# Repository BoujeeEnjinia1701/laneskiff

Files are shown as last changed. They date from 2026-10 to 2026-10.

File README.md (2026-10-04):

# LaneSkiff

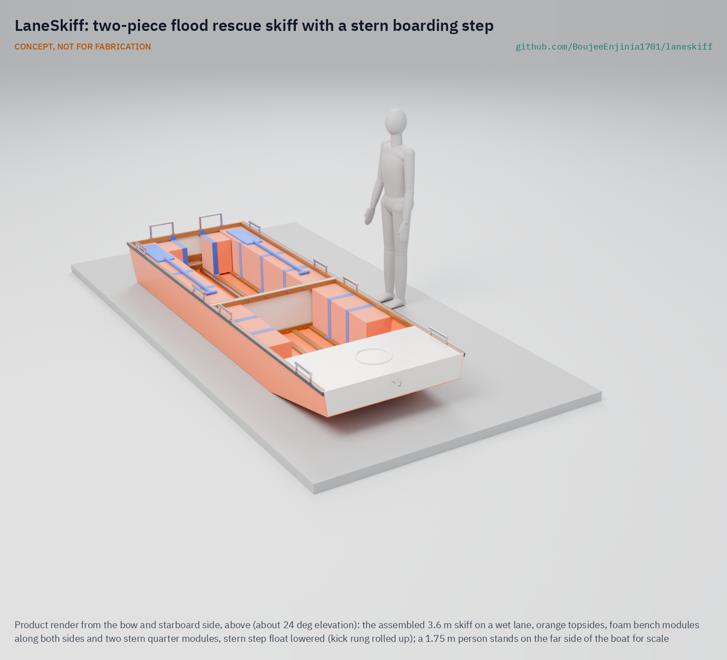
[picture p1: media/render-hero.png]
LaneSkiff: two-piece flood rescue skiff with a stern boarding step


     

**Area:** Situational field hardware · **TRL:** 3 of 9 (proof of concept on paper) · **Value-engineering target:** USD 1,500 (estimated cost of the constructable design USD 1,961) · **Difficulty:** 3 of 5

A flat-bottomed flood rescue boat two people carry into flooded lanes, with a floating stern step so people can climb in from waist-deep water.

> CONCEPT, NOT FOR FABRICATION. LaneSkiff is a TRL 3 design on paper: it has not been built or tested, and it is not certified rescue equipment.

## Concept rationale

Flood rescue in lanes is slow and awkward for boats built for open water. Hard boats are heavy to carry in, tip when someone climbs over the side, and sit too high for a person standing in waist-deep water. LaneSkiff is a flat-bottomed skiff sized for lanes: two people carry it in, and a crew pushes it along with a pole or paddles. A floating step at the stern centre lets people climb aboard over the end, where the boat is least likely to heel, and built-in buoyancy keeps it level and afloat even when it is swamped.

The hull splits into two rigid halves that bolt together, so it travels in a small vehicle and each half can be carried by one or two people. A material substitution table gives build paths in plywood and epoxy, aluminium sheet and plastic sheet, so local boatbuilders can make it with what they have. A fixed, forward-only fin drive is an optional add-on for longer transits; the core boat needs no engine. Payload is set at a realistic 5 to 8 times hull mass for a rigid hull.

## Burning platform

About 1.81 billion people, 23% of the world's population, are directly exposed to 1-in-100-year floods, and 89% of them live in low and middle income countries; India alone accounts for about 390 million ([Rentschler et al., Nature Communications, 2022](https://www.nature.com/articles/s41467-022-30727-4)). Drowning accounts for 75% of deaths in flood disasters ([WHO](https://www.who.int/health-topics/floods/drowning---key-facts)). In the 2018 Kerala floods about 800,000 people were displaced and many were stranded while rescuers worked with hundreds of boats ([CBS News, 2018](https://www.cbsnews.com/news/kerala-historic-floods-india-rescue-efforts-continue-hundreds-killed-2018-08-19/)).

The boats that exist are either costly, heavy or hard to board. A purpose-built inflatable rescue craft such as the Oceanid RDC costs USD 4,900 ([Oceanid](https://oceanid.com/RDC-Pricing-Specifications.html)). A 12 ft aluminium jon boat such as the Lund 1240 starts at USD 1,694 and weighs 107 lb (49 kg), but is rated for two people ([Lund](https://www.lundboats.com/families/jon-boat/1240.html)). Larger flood skiffs carry eight but weigh about 245 kg ([MetalBoatKits](https://metalboatkits.com/product/19-foot-6m-flood-rescue-skiff-new/)), too much to carry into a lane. None of them gives a person in waist-deep water a stable way in.

## Where it could be used

### By industry

| Industry | Use |
| --- | --- |
| Disaster response and civil defence | Lane-level evacuation where large boats cannot enter |
| Community and volunteer rescue groups | A boat local fishers and volunteers can build, store and carry to the flood |
| Humanitarian agencies | Prepositioned kits and local build programmes in flood-prone districts |
| Municipal services | Moving people, medicine and supplies through flooded streets |
| Small-scale fishing and boatbuilding | A design local boatyards can make and sell before the monsoon |
| Healthcare | Evacuating patients with limited mobility from flooded homes |

### By country or region

| Country or region | Why it matters there |
| --- | --- |
| India (Kerala) | The 2018 floods displaced about 800,000 people, with rescuers using hundreds of boats and nearly two dozen helicopters ([CBS News, 2018](https://www.cbsnews.com/news/kerala-historic-floods-india-rescue-efforts-continue-hundreds-killed-2018-08-19/)). |
| India (Bihar) | Villagers buy their own boats each flood season; small boats cost Rs 30,000 to 50,000 ([Gulf News, 2020](https://gulfnews.com/world/asia/india/india-floods-boost-boat-making-businesses-in-bihar-1.73026964)), so a cheaper, lighter local design matters. |
| Bangladesh | The August 2024 eastern floods affected 5.6 million people, with more than 500,000 seeking shelter as water submerged homes and streets ([UNICEF, 2024](https://www.unicef.org/press-releases/two-million-children-risk-worst-floods-three-decades-lash-through-eastern-bangladesh)). |
| Pakistan | The 2022 floods affected 33 million people and displaced 500,000 into relief camps ([UN News, 2022](https://news.un.org/en/story/2022/08/1125752)). |
| United States | In Hurricane Harvey, volunteer groups such as the Cajun Navy rescued people with jon boats, fishing boats, row boats, canoes and kayaks ([NBC News, 2017](https://www.nbcnews.com/storyline/hurricane-harvey/triumph-struggle-ragtag-cajun-navy-responds-houston-flood-n796991)), showing how much flood rescue relies on small craft. |

## What sparked the idea

During the Kerala floods of August 2018, Jaisal, a 32-year-old fisherman from Tanur in Malappuram, volunteered with a rescue team. Flat-bottomed boats are unstable and hard to board from the water, so he knelt in the floodwater and let women step on his back to climb in ([The Week, 2018](https://www.theweek.in/news/india/2018/08/20/kerala-fisherman-turns-stepping-stone-to-safety-literally.html)). His team rescued 17 families. LaneSkiff asks what boat would have made that sacrifice unnecessary: one with its own stable step, light enough to carry into the lanes where he worked.

## Problem

In urban and village floods, rescuers need a light boat they can carry into narrow flooded lanes, and people standing in waist-deep water need a way to climb into it without a rescuer kneeling as a step.

Full problem statement: [docs/01-problem.md](docs/01-problem.md)

## Concept

LaneSkiff is a flat-bottomed boat that two people carry into flooded lanes and push along with a pole or paddle. People in waist-deep water climb in using a floating step at the back, and it stays level and afloat even when swamped.

The constructable design is a 3.6 m punt-form skiff, 1.197 m wide over its rub strakes, stitched and glued from flat okoume plywood with softwood framing in two closed halves of 1.8 m that bolt together with eight M10 bolts and one spanner. Covered foam modules along both sides, two in the stern quarters and a foam bow box keep it nearly level when swamped (161 mm of freeboard at the transom). It is rated for five persons and draws 148 mm with them aboard. On paper, a person boarding over the stern step heels it 3.3 degrees, against 12.8 degrees over the side. The hull weighs 87.9 kg as drawn, still well over the 50 kg carry target, so each half is carried by two people with shoulder slings; see the [review note](docs/REVIEW.md).

Full design precis: [docs/02-concept.md](docs/02-concept.md) · Requirements: [docs/03-requirements.md](docs/03-requirements.md) · Calculations: [docs/04-calcs/01-sizing.md](docs/04-calcs/01-sizing.md) · Prototype build plan: [docs/05-build-plan.md](docs/05-build-plan.md) · Design decisions: [docs/06-design-decisions.md](docs/06-design-decisions.md)

## Key components

- Flat-bottom hull in two closed halves of okoume plywood and epoxy (6 mm bottom, 4 mm sides), each with its own bulkhead and softwood ring frame
- Eight M10 joint bolts into welded nut plates, two alignment pins
- Level flotation (LevelHull layout): covered foam bench modules along both sides and a foam bow box
- Stern-centre floating boarding step on strap hinges, with stop straps, a kick rung and two transom grab handles
- Eight carry handles and two padded shoulder slings
- Two-section push pole, two paddles, bow eye and bow line
- HDPE rub strakes and bottom skids
- Material substitution table: plywood and epoxy, aluminium sheet, HDPE sheet
- Optional fixed forward-only fin drive: not in the first prototype design (open decision)

## Building the prototype

The [prototype build plan](docs/05-build-plan.md) (LSK-BLD-001, plan, not yet built) shows a small boatyard how to build the first LaneSkiff component by component, with making sketches for fifteen made parts, close-ups of nine joints and a picture for each of seventeen assembly steps. The halves are stitched and glued from flat plywood panels, framed with softwood and glassed outside; the foam modules are cut with a knife and sewn into covers; the step is a glued float on strap hinges. No one is carried before the step, straps, handles and joint are proof-loaded and the boat passes load and swamp trials in calm, shallow water with a safety boat, which is TRL 4 work.

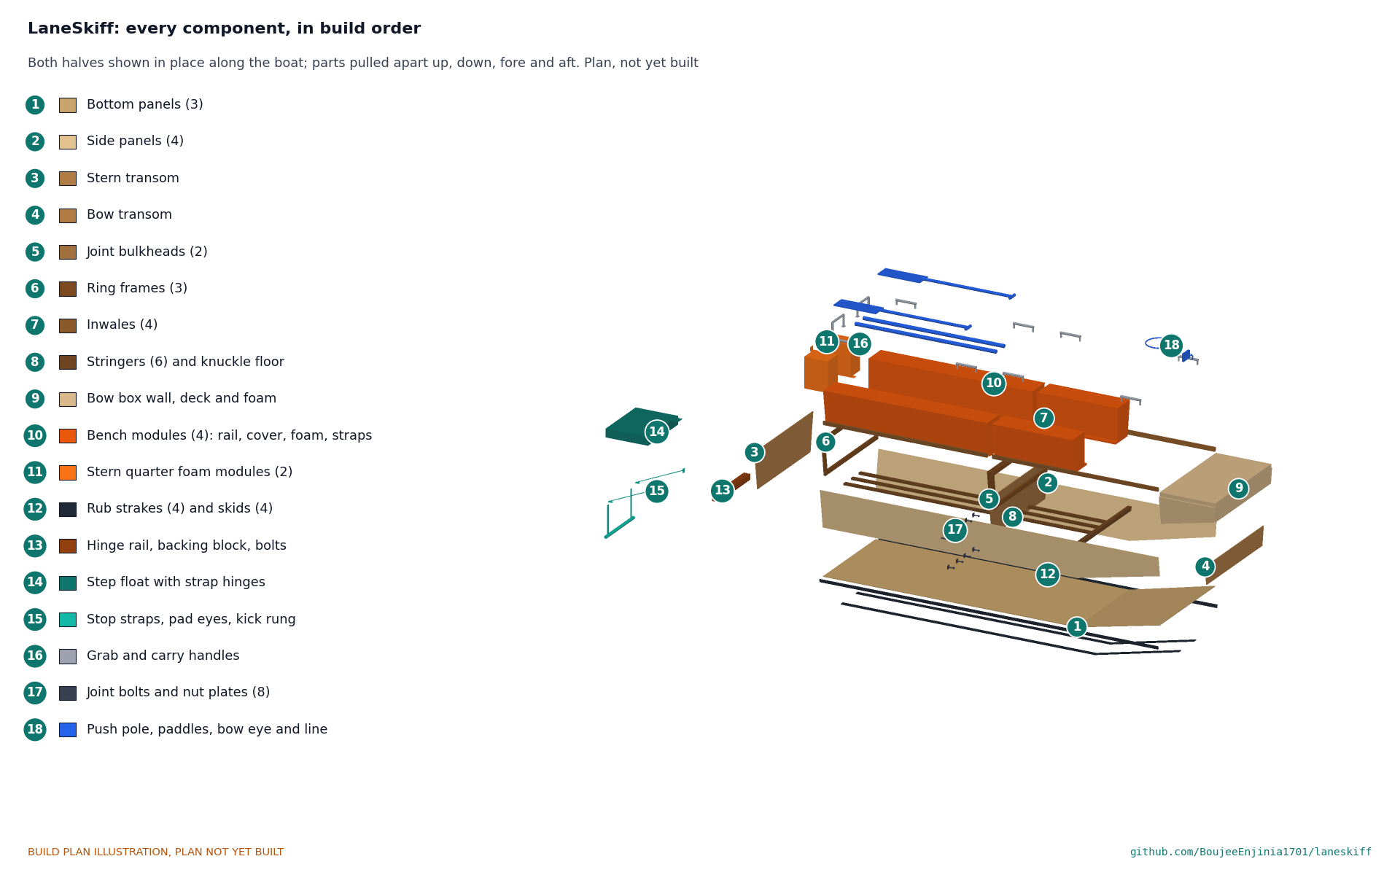
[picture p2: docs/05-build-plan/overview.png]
LaneSkiff build overview


## Safety

> Published as an open engineering reference, not a certified rescue boat.
>
> Crew and passengers wear life jackets at all times; crews need water rescue training under their own agency's rules.
>
> Not for swiftwater, surf, open water or water flowing faster than a person can wade against.
>
> Do not exceed the rated load for the build material; the payload differs between build paths.
>
> Watch for submerged hazards, open drains, live electrical wires and contaminated water.
>
> The boarding step swings on a hinge: a 40 mm gap keeps fingers and feet clear through its swing, and it is proof-loaded before any boarding trial.
>
> When swamped, people stay seated and low; two people moving to one side can dip the gunwale.
>
> This design is published as an open engineering reference. It is not certified equipment.

## Repository layout

| Folder | Contents |
| --- | --- |
| `docs/` | Problem, concept, requirements, calculations, build plan and design decisions |
| `cad/src/` | build123d Python source, the source of truth for all geometry |
| `cad/step/`, `cad/stl/` | Exported models for FreeCAD, other CAD tools and printing |
| `cad/drawings/` | 2D sketches and dimensioned drawings |
| `bom/` | Bill of materials |
| `electronics/` | KiCad schematics and PCB layouts |
| `firmware/` | Microcontroller code |
| `media/` | Renders, perspectives and photos |
| `build-log/` | Dated prototyping notes |

## Documentation

Controlled documents follow the portfolio [documentation standard](.kit/STANDARDS.md). Each carries a document ID (LSK-PRC-001 for the precis), a version and a revision history. Branded PDFs are built with `python .kit/render.py` and attached to GitHub Releases when a document is tagged, for example `LSK-PRC-001/v1.0`.

## Credits

Designed by Amish Chadha at Design Molecule Labs. See [CONTRIBUTORS.md](CONTRIBUTORS.md) for roles. To cite this design, use [CITATION.cff](CITATION.cff) (GitHub shows it as "Cite this repository").

AI assistance (Claude) was used to accelerate prototype documentation and first-pass research. Design direction and all decisions are Amish Chadha's, recorded in this repository's decision records (`docs/decisions/`).

## Licenses

- **Hardware** (CAD, drawings, BOM, electronics): [CERN-OHL-S v2](LICENSE)
- **Software** (firmware, scripts, notebooks): [MIT](LICENSE-SOFTWARE)

A project of the [Design Molecule](https://designmolecule.com) lab.

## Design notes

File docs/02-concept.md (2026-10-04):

---
doc_id: LSK-PRC-001
title: LaneSkiff design precis
project: LaneSkiff
doc_type: Precis
version: "0.3"
status: Draft
date: '2026-10-03'
author: Amish Chadha
license: CERN-OHL-S-2.0
revisions:
- version: "0.1"
  date: '2026-09-30'
  author: Amish Chadha
  change: Initial scaffold
- version: "0.2"
  date: '2026-10-03'
  author: Amish Chadha
  change: Concept formulated (TRL 2) and made constructable (TRL 3); components with BOM numbers, key design choices, first-order numbers, material table, safety
- version: "0.3"
  date: '2026-10-03'
  author: Amish Chadha
  change: 'Amish''s decisions 30A, 31C and 32A (LSK-DDR-003): light timber specification, five-person rating, bottom 60 mm wider, stern quarter foam and the aft-crew rule, no fin drive in the first prototype; numbers from LSK-CAL-001 v0.2'
---

# LaneSkiff design precis

A flat-bottomed flood rescue boat two people carry into flooded lanes, with a floating stern step so people can climb in from waist-deep water.

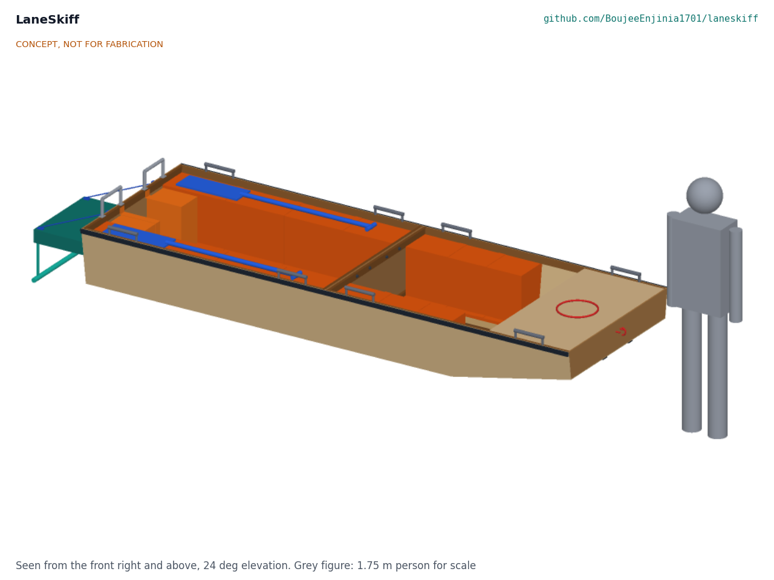
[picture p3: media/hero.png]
LaneSkiff concept, with a 1.75 m person for scale


*Figure 1. LaneSkiff assembled, stern step deployed, with a 1.75 m person for scale. CONCEPT, NOT FOR FABRICATION.*

## How it works

LaneSkiff is a punt-form skiff 3.6 m long and 1.197 m wide over its rub strakes, 0.40 m deep, built in two rigid halves of 1.8 m. Each half is a closed okoume plywood box with its own end panel and its own joint bulkhead, so each half floats on its own and the joint between them carries load but needs no seal. Eight M10 bolts join the halves through softwood ring frames on the two bulkheads; one spanner does it, because the nuts are welded to plates on the aft frame.

The bottom is flat for 2.7 m and rakes up to 200 mm at the bow, so the boat rides over kerbs and debris and can be poled in shallow water. The sides are flat plywood panels leaning out 8 degrees, which gives a wide waterline for stability and a narrow enough beam for lanes.

Buoyancy follows the LevelHull layout: closed-cell foam modules run along both sides under the inwales, and a foam-filled bow box sits under a short bow deck. Two 15 L foam modules stand in the stern quarters, either side of the step opening. When the boat is swamped, the foam is outboard and high enough that the boat floats nearly level with its rated persons aboard, and the aft crew member moves amidships.

At the stern centre, a buoyant step float lies on the water behind the transom, hinged to a hardwood rail. A kick rung hangs 270 mm below it on webbing. A person in waist-deep water puts a foot on the rung, takes the two transom grab handles, kneels on the float and rolls over the transom. Boarding over the end of the boat heels it about 3 degrees, against about 13 degrees for the same person climbing over the side. Stop straps hold the float at 20 degrees below level, and a 40 mm gap between float and rail keeps fingers and feet clear through its whole swing.

The crew poles the boat with a two-section push pole or paddles it. Eight carry handles, two at each end of each half, and two padded shoulder slings let people carry each half into a lane and join the halves at the water.

## Components

*Table 1. Components (BOM line numbers from `bom/bom.csv`).*

| BOM | Component | Role |
| --- | --- | --- |
| 1 | Bottom panels, 6 mm okoume plywood (aft, forward flat, bow rake), 1,060 mm wide at the chine | Flat bottom with a knuckle and bow rake; glass outside only |
| 2 | Side panels, 4 mm okoume plywood (4) | Flat sides flared 8 deg; full length of each half |
| 3, 4 | Stern transom (9 mm) and bow transom (9 mm) | Close the ends; the stern transom carries the step and grab handles |
| 5 | Joint bulkheads, 6 mm plywood (2) | Close each half at the joint so each half floats alone |
| 6 | Ring frames, softwood 20 x 45 (3) | Stiffen the transom and the bulkheads and take the joint bolts |
| 7 | Inwales, softwood 20 x 40 (4) | Stiffen the sheer; hold handles, strakes and the bench modules |
| 8 | Stringers (6) and knuckle floor | Stiffen the floor; take the skid screws; join the bottom at the knuckle |
| 9 | Bench modules and bow box | Foam in sewn tarpaulin covers, strapped to bench rails; bow box wall and deck |
| 10 | Buoyancy foam, closed-cell polyethylene | 0.56 m3 in the benches and bow box plus the step float core (LevelHull layout) |
| 29 | Stern quarter foam modules (2 x 15 L) | Keep the transom up when swamped; 250 mm clear between them for boarding |
| 11 | Joint bolts M10 x 80 with nut plates (8), alignment pins (2) | Join the halves with one spanner |
| 12, 13 | Rub strakes and bottom skids, HDPE | Protect the hull from walls, kerbs and debris |
| 14 | Stern step: hinge rail, backing block, float, strap hinges | Boarding platform on the water behind the transom |
| 15, 16 | Stop straps and pad eyes; kick rung on straps | Hold the step at 20 deg below level; first foothold below the float |
| 17, 18 | Transom grab handles (2) and carry handles (8) | Handholds for boarding; carrying each half or the whole boat |
| 19, 20, 21 | Push pole (two 1.5 m sections), paddles (2), bow eye and 10 m bow line | Propulsion and control in lanes; towing and holding at a doorway |
| 22 to 28 | Epoxy, glass, consumables, topcoat, screws, shoulder slings | Build materials and carrying slings |

The optional fixed, forward-only fin drive is not part of the first prototype design; whether and how to add it is an open decision for Amish (LSK-DEC-001). The material substitution table is in the first-order numbers below.

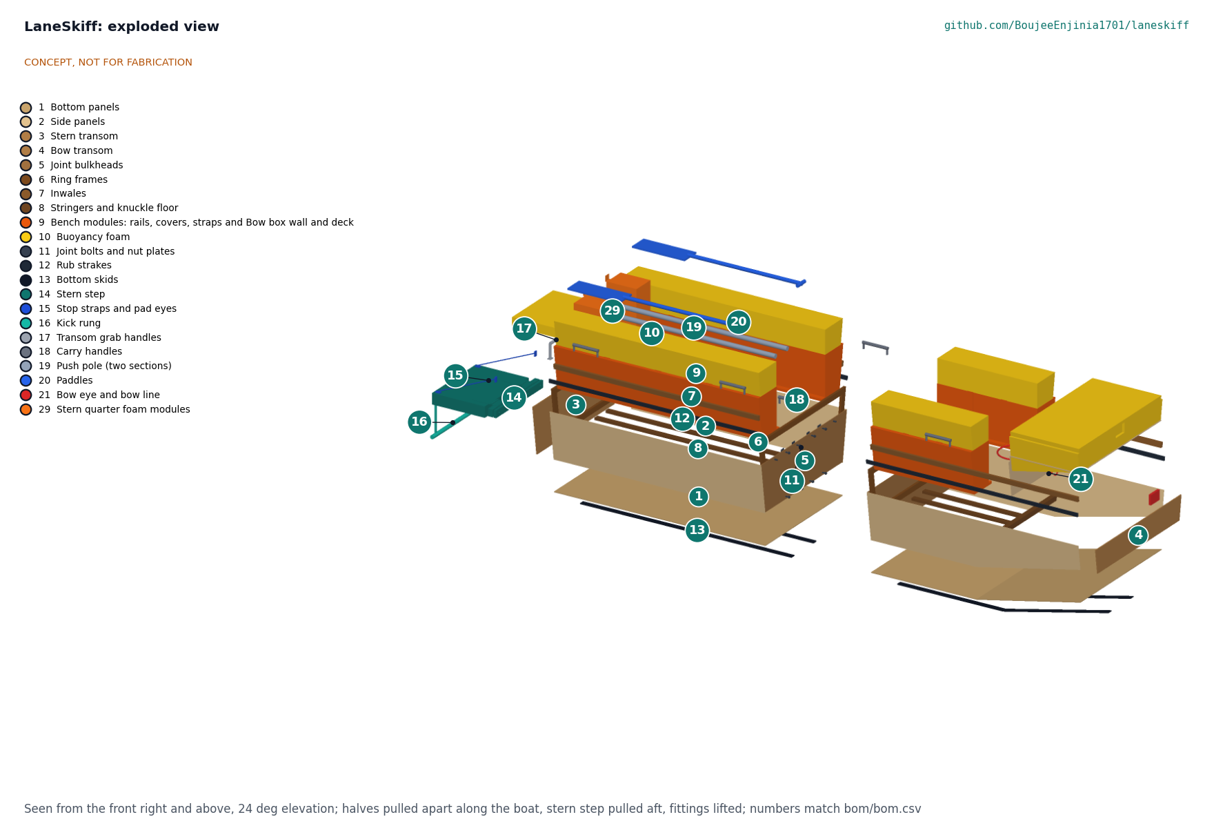
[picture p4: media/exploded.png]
Exploded view


*Figure 2. Exploded view: halves pulled apart along the boat, stern step pulled aft, fittings lifted. Numbers match the BOM.*

## Key design choices

Decided under Amish's pre-approval of 2026-10-03 (LSK-DDR-001 and LSK-DDR-002):

- **Punt form, constant width.** A flat bottom 1.0 m wide at the chine for 2.7 m, raked to the bow, with flat flared sides: the widest waterline and lowest draft for a lane-width beam, from flat panels a local yard can cut.
- **Two closed halves.** Each half has its own bulkhead, so the joint needs no seal and a half that is holed or loose still floats. The halves are bolted, not hinged or folded (the Porta-Bote design-around).
- **Plywood and epoxy first.** Stitch-and-glue is the most widely known small-boat method in coastal India and Bangladesh; aluminium and HDPE sheet paths are documented at concept level.
- **LevelHull buoyancy layout.** Foam outboard along the sides and forward, never low on the floor; no lift is credited to the plywood or timber.
- **Stern-centre boarding.** A float on the water and a kick rung below it, with transom handholds, after the expired US6932020B2 boarding platform.
- **Conservative safety choices.** Persons count at two thirds of their weight when swamped; the float swing is checked for pinch points; the step is proof-loaded before any boarding trial.

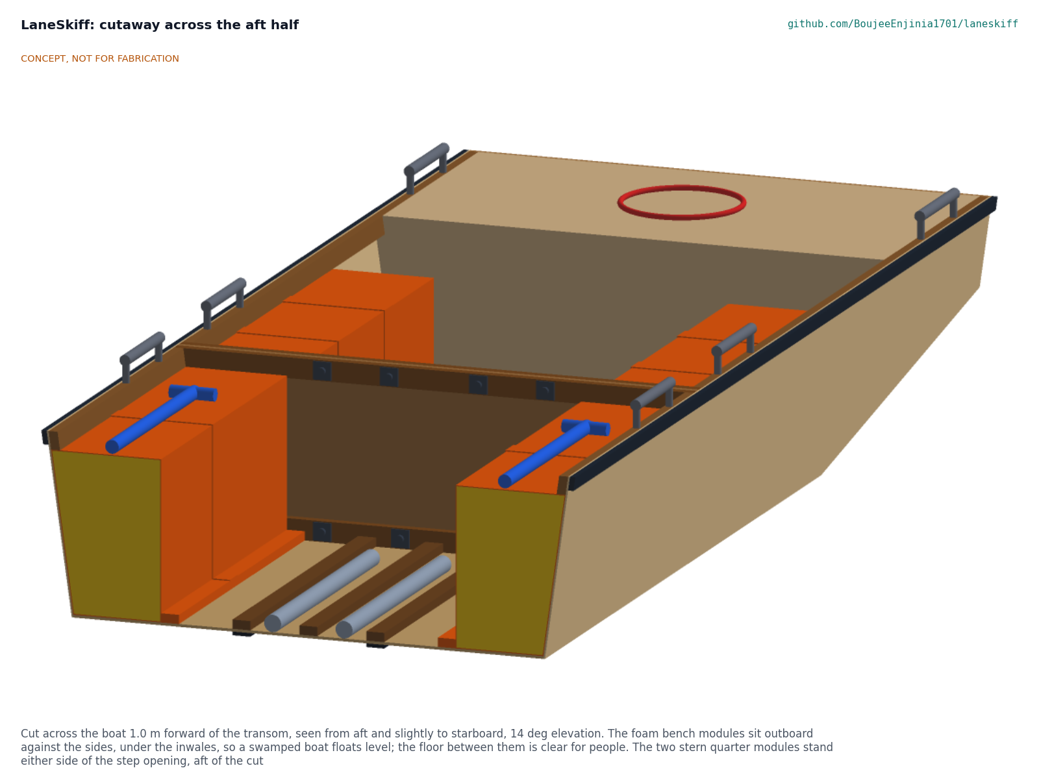
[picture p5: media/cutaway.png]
Cutaway across the aft half


*Figure 3. Cutaway across the aft half: the foam bench modules sit against the sides under the inwales; the floor between them is clear.*

## First-order numbers

From LSK-CAL-001 (`docs/04-calcs/01-sizing.md`); assumptions are stated there.

*Table 2. First-order numbers, plywood and epoxy path, light timber specification.*

| Quantity | Value |
| --- | --- |
| Length, beam over strakes, depth | 3.60 m, 1.197 m, 0.40 m |
| Hull mass as carried (pole, paddles and line not counted) | 87.9 kg; aft half 49.9 kg, forward half 38.1 kg |
| Rated load | Five persons, 375 kg (4.3 times hull mass) |
| Draft at rated load | 143 mm even keel; 148 mm at the transom, 138 mm at the forward end of the waterline |
| Draft with a crew of two | 79 mm |
| Heel boarding over the stern step; over the side | 3.3 deg; 12.8 deg |
| Swamped with rated persons | Afloat, trim 0.4 deg stern down, freeboard 161 mm at the transom and 188 mm at the bow; 216 mm at the transom with the aft-crew rule |
| Joining the halves | About 6 min, one 17 mm spanner (estimate) |
| Estimated cost of the constructable design | Value-engineering target: USD 1,500. Estimated cost of the constructable design: USD 1,961 (USD 461 over the target) |

*Table 3. Material substitution table (hull mass and load carried at 150 mm draft, same hull form).*

| Build path | Hull mass | Load at 150 mm draft | Load over hull mass |
| --- | --- | --- | --- |
| Okoume plywood and epoxy, softwood framing (prototype) | 88 kg | 401 kg | 4.6 |
| Aluminium 5052 sheet, 2.0 to 2.5 mm, welded or riveted | 101 kg | 388 kg | 3.8 |
| HDPE or polypropylene sheet, 5 to 8 mm, plastic welded | 111 kg | 377 kg | 3.4 |

The aluminium and plastic rows are screening estimates from panel areas; the framing, foam and fittings are the same as the plywood boat.

## Patent design-arounds

From the preliminary patent, trademark and prior-art screen (not legal advice):

- Single flat hull, poled or paddled; no twin pontoons with a jet ski transom and hinged ramp (US7832348B2, Newcomb, to 2028-10-24).
- Two rigid halves that bolt together; no flexible panel hull with a folding transom (US9061734B2, Porta-Bote, to 2029-12-30).
- No fin drive in the first prototype (Amish, decision 32A). A fin drive, if ever added, fixed and forward-only, following the expired US6022249 form; no rotating or 360 degree drive (US10259553B2 MirageDrive 360, to 2037-08-22).
- No reverse mechanism in any fin drive (Hobie US9359052 and US9981726, status unverified); never use MirageDrive or Hobie marks.
- Builds on lapsed prior art: US6932020B2 and US7011036B1 boarding platforms; EP0631552B1 and US7854211B2 nesting hulls.

## Shared blocks

- LevelHull (level-when-swamped buoyancy layout): foam modules outboard and high, in sewn covers.
- CalRig proof-load: the step hinge, stop straps, carry handles and bow eye are proof-loaded before trials.

## Safety

> **Safety:** LaneSkiff is published as an open engineering reference, not a certified rescue boat. Rescue in floodwater is hazardous: people can be swept off their feet, trapped under debris, cut, shocked by live wires or made ill by contaminated water.
>
> - Crew and passengers wear life jackets at all times; crews need water rescue training under their own agency's rules.
> - Not for swiftwater, surf, open water or water flowing faster than a person can wade against.
> - Do not exceed the rated load: five persons for the first prototype (Amish, decision 30A), marked on the transom; the payload differs between build paths.
> - Watch for submerged hazards, open drains, live electrical wires and contaminated water.
> - The boarding step has a hinge and a swinging float: the 40 mm gap keeps fingers and feet clear through its 20 degree swing, and nobody holds the hinge edge while the step is folded or unfolded.
> - When swamped, the aft crew member moves amidships and everyone stays seated, low and centred (LSK-CAL-001, section 4).
> - The step, stop straps, handles and bow eye are proof-loaded to twice their working load before any boarding trial, and the first swamp test is run in calm, shallow water with a safety boat (LSK-BLD-001, safety stops).

## Open questions

Open decisions and items to confirm are kept in the design decisions register, `docs/06-design-decisions.md` (LSK-DEC-001).

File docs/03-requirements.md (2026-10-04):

---
doc_id: LSK-REQ-001
title: LaneSkiff requirements
project: LaneSkiff
doc_type: Requirements
version: "0.4"
status: Draft
date: '2026-10-04'
author: Amish Chadha
license: CERN-OHL-S-2.0
revisions:
- version: "0.1"
  date: '2026-09-30'
  author: Amish Chadha
  change: Initial scaffold
- version: "0.2"
  date: '2026-10-03'
  author: Amish Chadha
  change: Rated load and test conditions stated; TRL 3 status from LSK-CAL-001; targets unchanged
- version: "0.3"
  date: '2026-10-03'
  author: Amish Chadha
  change: Amish's decisions 30A, 31C and 32A (LSK-DDR-003) carried out; rated load restated as five persons (375 kg); R5 states the stern quarter foam and the aft-crew rule; R10 left out of the first prototype; TRL 3 status from LSK-CAL-001 v0.2; numeric targets unchanged
- version: "0.4"
  date: '2026-10-04'
  author: Amish Chadha
  change: "R2 restated by Amish's round-3 decision 6A (LSK-DDR-004): payload 375 kg (five persons) within the R3 draft limit, ratio reported; met"
---

# LaneSkiff requirements

Requirements for the first prototype, built on the plywood and epoxy path in the light timber specification (okoume plywood, 4 mm sides, softwood framing). Numeric targets are those set at TRL 1 and are unchanged. On 2026-10-03 Amish decided the open requirement items (LSK-DDR-003): "i agree with all the 46 recommendations you provided. please proceed." Decision 30A sets the rated load at five persons, 31C adds stern quarter foam and the aft-crew rule to R5, and 32A leaves the fin drive out of the first prototype. Status is the paper result at TRL 3 from LSK-CAL-001; every requirement is verified by test at TRL 4. On 2026-10-04 Amish decided option 6A on R2: "For round 3, I agree with all your proposed recommendations". R2 is restated as "payload 375 kg (five persons) within the R3 draft limit; the payload-to-hull ratio is reported" (LSK-DDR-004). Where a requirement is not met or is at risk on paper, the state and the options are set out for Amish in `docs/REVIEW.md` and listed as open decisions in LSK-DEC-001.

*Table 1. Requirements.*

| ID | Requirement | Target | Verification (TRL 4) | TRL 3 status |
| --- | --- | --- | --- | --- |
| R1 | Carry mass | Complete hull 50 kg or less; each half 25 kg or less (plywood and epoxy path, target) | Weigh the prototype halves | Not met on paper: hull 87.9 kg, halves 49.9 and 38.1 kg; accepted by Amish with the light timber specification and shoulder slings (decision 30A) |
| R2 | Payload | Payload 375 kg (five persons) within the R3 draft limit; the payload-to-hull ratio is reported, not a pass mark (restated 2026-10-04, decision 6A) | Static load test with water ballast in calm water | Met on paper as restated: 375 kg at 148 mm draft, inside the 150 mm limit. Reported ratio: 4.3 times hull mass at the rated load; 401 kg fits within the R3 draft (4.6) |
| R3 | Draft at rated load | 15 cm or less at the rated load of five persons (375 kg), Amish, 2026-10-03, decision 30A: "i agree with all the 46 recommendations you provided. please proceed." | Measured at the transom and bow during the load test | Met on paper: 148 mm at the transom, 138 mm at the forward end of the waterline |
| R4 | Width for lanes | Beam 1.2 m or less overall | Tape measure; trial passage through a 1.3 m gate | Met: 1,197 mm over the rub strakes (3 mm margin after the 60 mm wider bottom) |
| R5 | Level flotation when swamped | Floats approximately level with rated persons aboard when fully swamped, using the ABYC H-8 test method (not certified); 30 L of foam in the stern quarters, and the aft crew moves amidships when swamped (operating rule), Amish, 2026-10-03, decision 31C: "i agree with all the 46 recommendations you provided. please proceed." | Swamp test in a pool following ABYC H-8 procedure, with and without the aft-crew rule | Met on paper: 0.4 deg trim and 161 mm freeboard at the transom with the foam alone; 216 mm at the transom and 141 mm at the bow with the rule as well |
| R6 | Boarding from waist-deep water | An 80 kg adult boards over the stern step unaided; heel stays under 10 degrees (target) | Boarding trials with several volunteers of different builds, inclinometer on the hull | Met on paper: 3.3 deg heel over the stern step (12.8 deg over the side for comparison) |
| R7 | Assembly | Two halves joined in 10 min or less by two people with one spanner | Timed assembly trial | Met on paper (estimate): about 6 min, one 17 mm spanner |
| R8 | Local build | At least two build paths (plywood and epoxy, aluminium or plastic sheet) documented with mass and payload | Build by a partner boatyard from the published drawings | Met on paper: three paths in the material substitution table (LSK-CAL-001, section 8) |
| R9 | Prototype cost | USD 1,500 or less including step, poles and paddles | Bill of materials and receipts | USD 1,961: over the value-engineering target by USD 461 |
| R10 | Optional fin drive | Removable in 5 min or less; the boat meets R2 to R6 without it. Not part of the first prototype, Amish, 2026-10-03, decision 32A: "i agree with all the 46 recommendations you provided. please proceed." | Trials with and without the drive fitted, once a drive exists | Not shown on paper: left out of the first prototype by decision; R2 to R6 are assessed without a drive |

## Definitions used for the TRL 3 status

- **Hull mass:** the complete boat with its stern step, handles, strakes, skids and buoyancy, as carried; the push pole, paddles and bow line are loose gear (6.2 kg) and not counted.
- **Rated load:** five persons at 75 kg (a crew of two and three adults, 375 kg), placed as in LSK-CAL-001, section 3; decided by Amish on 2026-10-03 (decision 30A) and marked on the transom.
- **Swamped:** both halves full to the outside water level, persons aboard counted at two thirds of their weight (a conservative design assumption, not the ABYC H-8 rule itself).
- **Draft:** from the water surface to the outside of the bottom, at the transom and at the forward end of the waterline.

## Assumptions

- Fresh floodwater, 1,000 kg/m3; calm, slow water.
- Okoume marine plywood of about 450 kg/m3 and softwood framing of about 500 kg/m3 (light timber specification, decision 30A); hardwood of about 700 kg/m3 only for the step, the bow eye pad and the rung.
- Closed-cell polyethylene foam of about 30 kg/m3 with under 1 % water uptake by volume is available near the first partner.
- Two people can carry about 40 to 50 kg between them over a short distance; four can carry the assembled boat.
- A stern-centre step heels the boat less than a side step; LSK-CAL-001 confirms this on paper, the boarding trials confirm it in water.

> **Safety:** LaneSkiff is an open engineering reference for a rescue boat, not certified equipment. Every trial behind R2, R3, R5 and R6 is run in calm, shallow water with a safety boat or bank team, every person in a life jacket, and the volunteers briefed; no trial uses moving water. The step hinge and stop straps are proof-loaded to twice their working load before any boarding trial. The boat carries no more than five persons; when swamped, the aft crew moves amidships and everyone stays seated, low and centred.

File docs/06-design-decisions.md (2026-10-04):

---
doc_id: LSK-DEC-001
title: LaneSkiff design decisions register
project: LaneSkiff
doc_type: Design decisions register
version: "0.3"
status: Draft
date: '2026-10-04'
author: Amish Chadha
license: CERN-OHL-S-2.0
revisions:
- version: "0.1"
  date: '2026-10-03'
  author: Amish Chadha
  change: Register opened; design choices decided under Amish's 2026-10-03 pre-approvals; requirements not met or at risk proposed for Amish's decision
- version: "0.2"
  date: '2026-10-03'
  author: Amish Chadha
  change: Open items 1 to 5 decided by Amish (30A, 31C, 32A; LSK-DDR-003) and moved to Decisions made; new open item on R2 after the five-person rating; items to confirm for okoume and softwood; cost updated
- version: "0.3"
  date: '2026-10-04'
  author: Amish Chadha
  change: "Open item 1 (R2) decided by Amish (round-3 decision 6A, LSK-DDR-004) and moved to Decisions made; no open decisions"
---

# LaneSkiff design decisions register

Every design decision still to be made, and every decision made, in one place. Each decision is argued in full in its decision record under `docs/decisions/` or, for the open items, in `docs/REVIEW.md` (TRL 3 section, Decisions for Amish); this register is the index Amish works from. The build plan (`docs/05-build-plan.md`) describes the design as it stands and does not list decisions.

> **Safety:** Several entries set safety limits: the step gap and stop, proof loads before trials, the swamped margin at the transom, and the rating of the boat. Each decided item takes the conservative option and names the evidence that would relax it. Amish set the rating at five persons and chose stern quarter foam with the aft-crew rule for the swamped margin (LSK-DDR-003).

## Open decisions

None. Items 1 to 5 of version 0.1 were decided on 2026-10-03 and the R2 question (open item 1 of version 0.2) on 2026-10-04; all are under Decisions made.

## To confirm when parts are bought

These are facts that can only be settled with real parts or the first partner. None changes a decision; each may change a size or a limit.

*Table 2. Items to confirm.*

| # | What to confirm | Why it matters | Source |
| --- | --- | --- | --- |
| 1 | Density of the okoume plywood and softwood actually available (450 and 500 kg/m3 assumed) | Hull mass (R1, R2) and draft (R3, 2 mm margin) | LSK-DDR-003 |
| 2 | Foam density about 30 kg/m3 and water uptake under 1 % by volume on the supplier's data sheet; then 30 days immersion of samples | Swamped freeboard (R5) | LSK-DDR-002, A2 |
| 3 | Strap hinge pin strength (4 kN each assumed); webbing breaking strength (8 kN assumed) | Step factors 1.5 and 4.2 | LSK-CAL-001, table 1 |
| 4 | Nut plate weld quality and the M10 bolt grade (A4-70) | Joint factor in the kerb case | LSK-DDR-002, C3 |
| 5 | Mass of the epoxy, glass and coating as applied (weigh the first half after glassing) | 13.6 kg assumed | LSK-DDR-002, A6 |
| 6 | Price of polyethylene foam and marine plywood near the first partner | Foam and plywood are about a third of the cost | `bom/bom.csv`, lines 1 to 5 and 10 |
| 7 | Body mass of the partner's crews and of the people they rescue (75 kg assumed) | Rated load and draft (R3 met by 2 mm at five persons) | LSK-CAL-001, A6 |
| 8 | Bending strength of the okoume plywood bought (40 MPa assumed), and floor wear with no glass inside | Floor factor 1.5 under a foot load | LSK-CAL-001, A9 and section 6 |
| 9 | Screw holding of the skid and strake screws in softwood stringers and inwales; nut plate bearing on the softwood joint frame (10 MPa assumed) | Skid and strake security; joint factor 5.9 | LSK-DDR-003 |
| 10 | Beam over the rub strakes as built (1,197 mm drawn, 1,200 mm limit) | R4, 3 mm margin | LSK-CAL-001, section 11 |

## Value engineering

Value-engineering target: USD 1,500 (a hypothetical control target, not a limit). Estimated cost of the constructable design: USD 1,961 (USD 461 over the target). Main cost drivers and savings worth trying:

- The largest lines are the foam (USD 385), the 6 mm okoume (USD 270 for three sheets), the epoxy (USD 175), the carry and grab handles (USD 100) and the stern step hardware (USD 75).
- Line 9 still prices two sheets of 4 mm plywood for bench boxes (USD 110), which LSK-DDR-002 replaced with tarpaulin covers and straps; repricing it as covers and straps (perhaps USD 60) is worth doing at the next BOM review.
- Savings worth trying: foam by the block from a fishing-float maker, cut locally (perhaps USD 100); rope or webbing carry loops in place of bought handles (about USD 80); local hardwood offcuts for the frames, rails and step rim (about USD 40); polyurethane-varnish coating on the inside faces in place of a second epoxy coat (about USD 50).
- A boatyard building a batch shares the stitching, fillet and glassing set-up across boats, which is where most of the labour goes.

## Decisions made

*Table 3. Decisions made.*

| Date | Decision | Decided by | Record |
| --- | --- | --- | --- |
| 2026-10-03 | TRL 2 review items D1 to D10: punt form 3.6 x 1.0 m bottom with bow rake and 8 deg flared sides; two closed halves; plywood and epoxy first, aluminium and HDPE paths at concept level; LevelHull buoyancy layout with no lift from timber and persons at two thirds when swamped; floating stern step with kick rung and transom handholds; calculations at six persons (450 kg); shoulder slings in place of yoke fittings; two-section pole; first co-design candidates (a Malappuram fishers' rescue group with a local boatyard, north Bihar boat makers, a state disaster response unit; none approached yet); targets unchanged; pitch, problem, design-arounds and budget unchanged | Amish, pre-approvals of 2026-10-03: "start with the first 14 repos from the list of 29 projects. I pre-approve the batch runs along with any recommendations you come up with. I also accept any cost overruns or variations from the assumed scope cost." and "Proceed with the remaining 15 scaffolds" | LSK-DDR-001 |
| 2026-10-03 | Design for construction, changes C1 to C13: stitch-and-glue panels with a bow knuckle; two bulkheads with ring frames; eight M10 bolts into welded nut plates and two pins; covered foam bench modules held by inwale, straps and bench rails; bow box; three stringers per half and a knuckle floor; inwales; hinge rail, float, strap hinges, 40 mm gap, stop straps and kick rung; 9 mm transom, 6 mm bulkheads; HDPE strakes and skids screwed into hardwood; handles and slings; two-section pole; bow U-bolt with pad | Amish, same pre-approvals | LSK-DDR-002 |
| 2026-10-03 | Assumptions A1 to A6: timber densities, foam data, persons at two thirds when swamped, fitting strengths, hinge gap, epoxy and glass rates | Amish, same pre-approvals | LSK-DDR-002 |
| 2026-10-03 | Step hinge gap 40 mm and stop at 20 deg below level (conservative; narrowed only after a pinch check with test fingers and a boot) | Amish, same pre-approvals | LSK-DDR-001, D5 |
| 2026-10-03 | No person carried before the step, stop straps, handles, bow eye and joint are proof-loaded to twice their working load, and no boarding or swamp trial except in calm, shallow water with a safety boat and every person in a life jacket (a gate, not relaxed) | Amish, same pre-approvals | LSK-BLD-001, sections 5 and 6 |
| 2026-10-03 | R1, R2 and R3 (decision 30A): light timber specification (okoume plywood, 4 mm sides, softwood framing, no glass inside the floor), a five-person rating (375 kg) and a bottom 60 mm wider; halves carried with the shoulder slings | Amish, 2026-10-03: "i agree with all the 46 recommendations you provided. please proceed." | LSK-DDR-003 |
| 2026-10-03 | R5 (decision 31C): 30 L of foam in the stern quarters (two 15 L modules either side of the step opening) and the aft-crew rule | Amish, 2026-10-03: "i agree with all the 46 recommendations you provided. please proceed." | LSK-DDR-003 |
| 2026-10-03 | R10 (decision 32A): no fin drive in the first prototype; an open fixed forward-only drive kept as a later portfolio idea | Amish, 2026-10-03: "i agree with all the 46 recommendations you provided. please proceed." | LSK-DDR-003 |
| 2026-10-03 | Appearance model departures: orange painted topsides and light grey inside, a wet concrete lane slab and a 1.75 m mannequin on the far side of the boat, kick rung left out of the hero (rolled up on land), and a cut-back stern for the detail view, drawn for the renders only | Amish, same pre-approvals | `docs/REVIEW.md`, TRL 3 section |
| 2026-10-04 | R2 (6A): restated as "payload 375 kg (five persons) within the R3 draft limit; the payload-to-hull ratio is reported"; met at 375 kg and 148 mm draft, ratio 4.3 reported | Amish: "For round 3, I agree with all your proposed recommendations" | LSK-DDR-004 |

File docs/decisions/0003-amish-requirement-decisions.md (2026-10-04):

---
doc_id: LSK-DDR-003
title: LaneSkiff requirement decisions of 2026-10-03
project: LaneSkiff
doc_type: Design decision record
version: "0.1"
status: Draft
date: '2026-10-03'
author: Amish Chadha
license: CERN-OHL-S-2.0
revisions:
- version: "0.1"
  date: '2026-10-03'
  author: Amish Chadha
  change: Amish's decisions 30A, 31C and 32A recorded and carried out in the model, calculations, drawings and build plan
---

# 0003: Requirement decisions of 2026-10-03

- **Date:** 2026-10-03
- **Status:** accepted. Decided by Amish on 2026-10-03: "i agree with all the 46 recommendations you provided. please proceed."

## Context

The TRL 3 sizing (LSK-CAL-001 v0.1) left five open items in LSK-DEC-001: R1 carry mass (hull 100 kg), R2 payload ratio (4.5 at six persons), R3 draft (187 mm at six persons), R5 swamped margin (36 mm at the transom) and R10 fin drive (not designed). The state, options and recommendations were put to Amish in `docs/REVIEW.md`. He accepted every recommendation; in the portfolio's numbering they are 30A (items 1 to 3), 31C (item 4) and 32A (item 5).

## Options considered

The options for each item are in `docs/REVIEW.md` (TRL 3 section, "Decisions for Amish") and in LSK-CAL-001 v0.1, section 9. In short: for mass, a light timber specification, carrying with four people, or a shorter hull; for draft, a five-person rating with or without a wider bottom, or keeping six persons; for the swamped margin, stern quarter foam, an operating rule, or both; for the fin drive, leaving it out, a bracket for a bought drive, or an open drive as a separate project.

## Decision

*Table 1. Decisions and what was changed.*

| # | Decision | Changed in the design | Result (LSK-CAL-001 v0.2) |
| --- | --- | --- | --- |
| 30A | Light timber specification: okoume plywood (about 450 kg/m3), 4 mm sides, softwood framing (about 500 kg/m3), no glass inside the floor; a five-person rating (375 kg); the bottom 60 mm wider; each half carried with the shoulder slings | `half_bot` 500 to 530 mm and `t_side` 6 to 4 mm in `cad/src/model.py`; densities and inside glass in `docs/04-calcs/sizing.py`; plywood, framing, glass, epoxy and foam lines in `bom/bom.csv`; rating in LSK-REQ-001 | Hull 87.9 kg (was 100.2), halves 49.9 and 38.1 kg; deepest draft 148 mm at five persons (R3 met); beam 1,197 mm (R4 met, 3 mm margin); rated load 4.3 times hull mass (R2 not met) |
| 31C | 30 L of foam in the stern quarters, and the aft-crew rule (the aft crew member moves amidships when swamped) | Two 15 L foam modules (250 x 190 x 316 mm cores) in tarpaulin covers, either side of the step opening, on the side stringer and bench rail, strapped to the transom ring frame and the stringer (BOM line 29); the rule in the build plan and the requirements | Swamped transom freeboard 161 mm with the foam alone, 216 mm with the rule as well (was 36 mm); R5 met on paper |
| 32A | Leave the fin drive out of the first prototype; an open fixed forward-only fin drive stays a later portfolio idea | Nothing in the prototype; R10 restated | R10 not shown; R2 to R6 assessed without a drive |

## Consequences

- Nine constructability checks were added (82 of 82 pass): the quarter modules sit on the stringer and bench rail, their straps reach the ring frame and stringer, they leave 250 mm clear between them at the step opening, they clear the stowed pole, and the beam stays within 1,200 mm.
- The aft crew still stands at 0.4 m from the transom, forward of the quarter modules (which end 0.30 m from the transom).
- The R1 carry mass is still not met; Amish accepted this with the decision. The R2 payload ratio falls to 4.3 because the rating is now five persons; this is put to Amish as a new question in `docs/REVIEW.md` and LSK-DEC-001.
- Estimated cost rises by USD 39 to USD 1,961 (value-engineering target USD 1,500; USD 461 over).
- Okoume and softwood are weaker and softer than the gurjan and hardwood assumed before: the plywood bending strength, the screw holding of the skid and strake screws in softwood, and the nut plate bearing on the softwood joint frame are added to the items to confirm.
- The general arrangement goes to Rev P3; a making sketch for the quarter module (LSK-DWG-115) and a joint close-up (joint 9) are added; every making sketch, joint, step picture and the concept media are regenerated from the changed model.

## Safety

> **Safety:** The rating is five persons and is marked on the transom; six persons put the draft back to 177 mm. When the boat is swamped, the aft crew member moves amidships and everyone stays seated, low and centred. The stern quarter foam gives margin even when the rule is not followed. The proof loads and trial gates of LSK-BLD-001 are unchanged.

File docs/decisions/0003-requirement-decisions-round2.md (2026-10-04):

---
doc_id: LSK-DDR-003
title: LaneSkiff requirement decisions, round 2
project: LaneSkiff
doc_type: Design decision record
version: "0.1"
status: Draft
date: '2026-10-03'
author: Amish Chadha
license: CERN-OHL-S-2.0
revisions:
- version: "0.1"
  date: '2026-10-03'
  author: Amish Chadha
  change: Five requirement decisions (R1, R2, R3, R5, R10) decided by Amish on 2026-10-03 as recommended, and carried into the design
---

# 0003: Requirement decisions, round 2

- **Date:** 2026-10-03
- **Status:** Decided
- **Decided by:** Amish Chadha, 2026-10-03

## Context

The TRL 3 review (`docs/REVIEW.md`, Session 2026-10-03: TRL 3, Decisions for Amish) posed five requirements that were not met, at risk or not shown on paper as decisions for Amish, each with its state, options and a recommendation: R1 carry mass, R2 payload ratio, R3 draft at rated load, R5 swamped margin at the transom and R10 the optional fin drive. On 2026-10-03 Amish wrote: "i approve all of the 47 recommendations provided by you. Execute them." Each of the five is therefore decided as its recommendation, exactly as worded, and carried into the design at TRL 3 scope only: model, calculations, bill of materials, drawings, build plan and documents. Nothing here is built or tested; the conditions below are checked at TRL 4.

The decisions are linked. R1 A (the light timber specification, with the slings) also settles R2 A, and R3 B takes the same light specification with a five-person rating and a bottom 60 mm wider. The five-person rating changes every result that depends on the rated load or the swamped buoyancy, so all of them were recomputed in LSK-CAL-001 v0.2 on the decided design together, not added option by option.

> **Safety:** Decision 4 (R5) is a safety item. The operating rule that the aft crew member moves amidships when the boat is swamped is printed on a capacity plate on the inside of the transom (BOM line 30) with the five-person rating, and is in the README operating notes and the build plan safety stops. The stern quarter foam gives margin even if the rule is not followed.

## Options considered

The options for each decision are set out in full in `docs/REVIEW.md` (Session 2026-10-03: TRL 3, Decisions for Amish). Table 1 lists the option chosen.

## Decision

*Table 1. Decisions of 2026-10-03, with their effect on the decided design (LSK-CAL-001 v0.2, paper estimates).*

| # | Requirement | Option chosen | Effect | Condition |
| --- | --- | --- | --- | --- |
| 1 | R1, carry mass | A, with the slings: light timber specification (okoume plywood about 450 kg/m3, 4 mm sides, softwood framing about 500 kg/m3, no glass inside the floor), each half carried by two people with the shoulder slings | Hull 88.0 kg (100.2 kg before), halves 49.9 and 38.1 kg; 25.0 and 19.0 kg for each of two carriers per half. The light specification saves about 18 kg as estimated; the wider bottom of decision 3 and the extra foam of decision 4 put back about 6 kg. R1 (50 kg) still not met | Okoume and softwood at the assumed densities near the first partner; less abrasion margin on the floor; floor bending factor 1.5 assumes 40 MPa plywood; joint nut plates now bear on softwood (factor 3.5, estimate) |
| 2 | R2, payload ratio | A, taken together with R1 A | With the five-person rating of decision 3 the ratio is 375 / 88.0 = 4.26 (4.49 before). The option's 5.45 assumed six persons on an 83 kg hull; at six persons this hull would give 5.11 but a 177 mm draft. R2 not met, and further from the target than before | A new question is posed: no rating meets R2 and R3 together on this hull |
| 3 | R3, draft at rated load | B: light specification and a five-person rating (375 kg), with the bottom 60 mm wider (1,060 mm at the chine) | Deepest draft 148 mm at the transom, 138 mm at the forward end of the waterline (187 mm before); beam 1,197 mm over the rub strakes, R4 still met; transverse GM at rated load 0.31 m (0.15 m before). R3 met on paper with a 2 mm margin | The five-person rating goes on the capacity plate; crew and passenger masses near 75 kg (to confirm with the partner) |
| 4 | R5, swamped margin at the transom (safety) | C: two 15 L covered stern quarter foam modules, and the operating rule that the aft crew member moves amidships when swamped | With five persons, quarter foam and nobody moving: trim 0.45 deg stern down, transom freeboard 160 mm. With the rule as well: 215 mm. For comparison, without either (five persons, lighter hull) 115 mm; before the decisions 36 mm. Two people moving to one side swamped leave 38 mm at the low gunwale (it dipped before). R5 met on paper | The rule is printed on the capacity plate and taught to crews; the modules are strapped so they cannot lift off when swamped |
| 5 | R10, optional fin drive | A, with C kept as a later idea for the portfolio | No fin drive in the first prototype; no cost or mass. R10 stays not shown on paper. An open fixed forward-only fin drive after the expired US6022249 is recorded as a separate, later portfolio idea, not started | None for this prototype |

Placement of the stern quarter modules. The TRL 3 review described the modules as "high in the stern quarters, either side of the step opening". The outboard stern quarters are already filled by the aft bench modules, so each module stands inboard of its bench module at the transom end, from the side stringer and bench rail up to the bench top (209 x 226 x 334 mm outside, 15 L of foam), 40 mm forward of the transom to clear the hinge rail bolt nuts, held by two webbing straps from the floor over the module and the bench top to the inwale. Standing on the stringer it is submerged over most of its height when swamped, so it gives more lift than a module placed high would; the standing crew member's place 400 mm forward of the transom stays clear.

## Consequences

- `cad/src/model.py`: bottom half width 500 to 530 mm, side panels 6 to 4 mm, two stern quarter modules (cover, foam, straps). All 80 constructability checks pass (73 before; seven new contact checks for the modules). STEP and STL re-exported.
- `docs/04-calcs/sizing.py`, `01-sizing.md` (LSK-CAL-001 v0.2) and `results.csv`: okoume, softwood and no inside glass; five persons; swamped cases with and without the rule and the quarter foam; nut plate bearing on softwood.
- `bom/bom.csv`: plywood lines 1 to 5 as okoume (priced at about 1.4 times the plywood before, an estimate), framing lines 6 to 8 as softwood, line 10 seven foam sheets, line 23 glass outside only, new line 29 (stern quarter module covers and straps) and line 30 (capacity plate). Estimated cost USD 2,098 (USD 1,922 before), USD 598 over the value-engineering target; `budget_usd` stays at 1,500.
- `LSK-DWG-001` Rev P3; `LSK-DWG-101` to `110` Rev P2; build plan pictures, concept media and `media/model.glb` regenerated.
- `docs/03-requirements.md` v0.3 (rated load five persons; targets unchanged), `docs/02-concept.md` v0.3, `docs/05-build-plan.md` v0.2, `README.md` (with operating notes).
- New questions raised by these decisions are posed in `docs/REVIEW.md` and the design decisions register.

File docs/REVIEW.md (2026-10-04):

# Review note: LaneSkiff

## Session 2026-09-30: scaffolded

### What was done

- Repository created from kit 1.6.0 at TRL 1, target TRL 2.
- `docs/01-problem.md` (LSK-PRB-001 v0.1): problem with cited evidence, users, environment, constraints, prior work, open questions.
- `docs/02-concept.md` (LSK-PRC-001 v0.1): how it works, components, patent design-arounds, shared blocks, safety.
- `docs/03-requirements.md` (LSK-REQ-001 v0.1): 10 proposed requirements.
- `README.md` with concept rationale, burning platform, where it could be used, and what sparked the idea.

### Next

- Run `/populate` to bring the repo to a strong TRL 2 with concept media.

## Session 2026-10-03: TRL 2 (populate)

Run as the first half of `/to-trl3` under Amish's pre-approvals of 2026-10-03: "start with the first 14 repos from the list of 29 projects. I pre-approve the batch runs along with any recommendations you come up with. I also accept any cost overruns or variations from the assumed scope cost." and "Proceed with the remaining 15 scaffolds". Kit 1.7.0 installed.

### What was done

- `docs/01-problem.md` (LSK-PRB-001 v0.2): constraints restated with the value-engineering target, open questions answered, first co-design candidates, safety section.
- `docs/02-concept.md` (LSK-PRC-001 v0.2): how it works, components with BOM numbers, key design choices, first-order numbers, material substitution table, design-arounds kept, safety.
- `docs/03-requirements.md` (LSK-REQ-001 v0.2): ten requirements, targets unchanged, with TRL 3 status and definitions.
- Concept media from `cad/src/concept_media.py`: `media/hero.png` (1.75 m person for scale), `media/cutaway.png`, `media/exploded.png` (BOM callouts), `media/concept-blueprint.png`, `.pdf` and `.svg` (LSK-DWG-010), `media/model.glb` (1.1 MB, coarse tessellation) and `media/viewer.html`. No flow diagram: the boat carries people but moves no energy or material.
- `bom/bom.csv`: 28 priced lines.

### Results

- Level flotation works with the LevelHull layout (foam outboard and forward); stern-centre boarding heels the boat a quarter as much as boarding over the side.

### Requirements not met

- R1, R2 and R3 are not met and R5 is at risk; R10 is not shown. See the TRL 3 section.

### Decisions made under the pre-approval

LSK-DDR-001, items D1 to D10: punt form; two closed halves; plywood and epoxy first; LevelHull layout with conservative accounting; floating stern step with a 40 mm hinge gap and 20 degree stop; calculations at six persons; slings in place of yoke fittings; two-section pole; first co-design candidates (not approached); targets unchanged.

### Safety concerns

- Flood rescue is hazardous whatever the boat: life jackets, training, no moving water, and a safety boat for every trial.

## Session 2026-10-03: TRL 3 (advance and build plan)

Run as the second half of `/to-trl3` under the same pre-approvals, which count as the TRL 2 approval. Not committed or pushed (batch run).

### What was done

- `cad/src/model.py`: parametric build123d model of both halves, the joint hardware, the stern step and the outfit; 73 of 73 constructability checks pass (no overlaps between any two parts; every part touching the part it is fixed to; joint bolts through both frames and both bulkheads and clear of benches and stringers; rail bolts and bow eye through what they clamp; only bolts and pins cross the joint plane; the step float clear of rail and transom at its 20 degree stop and folded up; beam within 1.2 m). Exports `cad/step/laneskiff-assembly.step`, `laneskiff-aft-half.step`, `laneskiff-forward-half.step`, `laneskiff-stern-step.step`, six panel STEP files, and STL of a ring frame, the knuckle floor and the hinge rail.
- `docs/04-calcs/01-sizing.md` (LSK-CAL-001 v0.1) with `docs/04-calcs/sizing.py` and `results.csv`: masses, hydrostatics, swamped flotation, boarding heel, structure, joining time, build paths, option estimates and cost.
- `cad/src/sheets.py`: general arrangement `cad/drawings/LSK-DWG-001` (SVG, PDF, PNG) at Rev P2 with section A-A at 1:10.
- `cad/src/build_plan_media.py`: `docs/05-build-plan/overview.png`, 14 making sketches `cad/drawings/LSK-DWG-101` to `114`, 8 joint close-ups and 17 step pictures.
- `docs/05-build-plan.md` (LSK-BLD-001 v0.1), `docs/06-design-decisions.md` (LSK-DEC-001 v0.1), `docs/decisions/0001-trl2-review-decisions.md` (LSK-DDR-001) and `docs/decisions/0002-design-for-construction.md` (LSK-DDR-002).
- `cad/src/product_model.py` (appearance model) and render scenes exported with `.kit/export_views.py` to `/home/claude/renders/laneskiff` for hero, exploded and detail views; photoreal renders and cards are made on Amish's Mac.
- `project.yaml`: trl 3, trl_target 3, `design_state: constructable`, evidence listed; `budget_usd` unchanged. README leads with `media/render-hero.png` and has a "Building the prototype" section.

### Results

- Hull 3.60 m long, 1,137 mm over the rub strakes, 400 mm deep; 100 kg as carried (aft half with the step 56 kg, forward half 45 kg); plywood 35 kg, hardwood 22 kg, foam 15 kg, glass and epoxy 14 kg.
- Rated load assessed at six persons (450 kg, 4.5 times hull mass): 175 mm draft on an even keel, 162 mm at the transom and 187 mm at the forward end of the waterline; 87 mm with a crew of two; 361 kg carried within 150 mm of draft.
- Boarding over the stern step: 4.3 deg heel, 270 mm transom freeboard; over the side: 15.6 deg.
- Swamped with the rated persons (at two thirds of their weight): afloat, 2.1 deg stern down, freeboard 36 mm at the transom and 164 mm at the bow; two people moving 400 mm to one side dip the gunwale.
- Joining the halves: about 6 minutes, one spanner (estimate). Factors: floor 1.5, joint bolt 9.0 and nut plate 5.0 in a kerb case, stop strap 4.2, hinge 1.5.
- Build paths: plywood 100 kg, aluminium 98 kg, HDPE 110 kg (screening).
- Value-engineering target: USD 1,500. Estimated cost of the constructable design: USD 1,922 (USD 422 over the target).

### Requirements not met

- R1 not met (100 kg; halves 56 and 45 kg), R2 not met (4.5), R3 not met (187 mm), R5 at risk (36 mm at the transom), R10 not shown. Each is set out below for Amish's decision.
- R9: over the value-engineering target by USD 422; reported against the target (STANDARDS section 18), accepted under the pre-approval, and not put as a budget decision.
- The test half of R2 to R8 is TRL 4 work.

### Decisions for Amish

Each item is Proposed, awaiting Amish, and listed in LSK-DEC-001 as an open decision. Estimates are from LSK-CAL-001, section 9.

**R1, carry mass.**
- *State:* hull 100 kg as carried; aft half 56 kg, forward half 45 kg. Cause: closed-box halves with level-flotation foam (15 kg) and glass and epoxy (14 kg) in 600 kg/m3 plywood and 700 kg/m3 hardwood.
- *Option A, light timber specification:* okoume plywood (about 450 kg/m3), 4 mm sides, softwood framing (about 500 kg/m3), no glass inside the floor. Hull about 83 kg (halves 46 and 37 kg); still not met but 18 kg closer; cost about USD 100 more (okoume dearer); less abrasion margin on the floor.
- *Option B, keep the specification:* hull 100 kg; each half carried by two people with the shoulder slings (about 28 and 23 kg each) or the whole boat by four; no cost or mass change.
- *Option C, shorter hull:* 3.0 m in two 1.5 m halves; about 85 kg (rough estimate), about USD 100 less, rated load falls to about five persons.
- **Recommendation: A**, with the slings: the largest mass saving that keeps the hull form, the rating and the step unchanged.

**R2, payload ratio.**
- *State:* 450 kg rated load is 4.5 times hull mass. Cause: the 100 kg hull (R1).
- *Option A, light timber specification (as R1 A):* ratio about 5.45; cost about USD 100 more; mass 18 kg less.
- *Option B, accept the ratio:* 4.5 at six persons; no cost or mass change.
- **Recommendation: A**, taken together with R1 A.

**R3, draft at rated load.**
- *State:* 187 mm at the forward end of the waterline and 162 mm at the transom with six persons. Cause: a 450 kg load plus a 100 kg hull on a 3.5 x 1.05 m waterline.
- *Option A, light specification and a five-person rating (375 kg):* about 154 mm; cost about USD 100 more; mass 18 kg less.
- *Option B, as A with the bottom 60 mm wider:* about 145 mm; beam about 1,197 mm (R4 still met); a further USD 20 and 3 kg.
- *Option C, keep six persons:* 187 mm; no cost or mass change; the boat needs deeper water to carry a full load.
- **Recommendation: B**: meets R3 on paper with the smallest change to the concept.

**R5, swamped margin at the transom.**
- *State:* afloat with the rated persons, 2.1 deg stern down, 36 mm freeboard at the transom (164 mm at the bow). Cause: the standing crew member, transom and step are aft while the bow box puts foam forward.
- *Option A, stern quarter foam:* two 15 L covered foam modules high in the stern quarters, either side of the step opening; transom freeboard about 113 mm, trim about 0.4 deg; about 1 kg and USD 30.
- *Option B, operating rule:* the aft crew member moves amidships when the boat is swamped; transom freeboard 109 mm, trim 0.0 deg; no cost or mass.
- *Option C, both A and B.*
- **Recommendation: C**: the foam gives margin even when the rule is not followed, and the rule costs nothing.

**R10, optional fin drive.**
- *State:* no fin drive in the first prototype design, so its removal time and the boat's performance with it cannot be shown. Cause: the drive is an add-on and was not designed at TRL 3.
- *Option A, leave it out of the first prototype:* no cost or mass; R10 stays unshown until a drive exists.
- *Option B, clamp-on bracket for a bought pedal fin drive:* perhaps USD 800 to 1,500 and 7 to 10 kg; needs a patent and mark check of the chosen product (no MirageDrive or Hobie marks, no reverse or 360 degree mechanism).
- *Option C, an open fixed forward-only fin drive after the expired US6022249, as its own project:* no cost to this prototype; a separate design effort.
- **Recommendation: A**, with C kept as a later idea for the portfolio.

### Decisions made under the pre-approval

- LSK-DDR-002: design for construction, changes C1 to C13 and assumptions A1 to A6.
- Step hinge gap 40 mm and stop 20 deg below level (conservative).
- No person carried before the proof loads, and no trial except in calm, shallow water with a safety boat and life jackets.
- Appearance model departures (renders only): orange painted topsides and light grey inside; a wet concrete lane slab under the boat; a 1.75 m mannequin standing on the far side of the boat; the kick rung left out of the hero view (rolled up on land); a cut-back stern for the detail view.

### Build plan findings

- Design changes for construction (2026-10-03), all in LSK-DDR-002: stitch-and-glue panels with a bow knuckle; two bulkheads with hardwood ring frames; eight M10 bolts into welded nut plates and two pins; covered foam bench modules held by the inwale, straps and bench rails (plywood bench boxes dropped, about 9 kg saved); a foam bow box; three stringers per half and a knuckle floor; inwales; a hinge rail with backing block, float, strap hinges, 40 mm gap, stop straps and kick rung; 9 mm transom and 6 mm bulkheads; HDPE strakes and skids screwed into hardwood; handles and slings; a two-section pole; a bow U-bolt with pad.
- The floor needs the centre stringer: without it the span is 255 mm and the factor under a foot load falls below 1.
- Items to confirm with real parts (timber and foam densities, hinge and webbing strengths, nut plate welds, epoxy mass, foam and plywood prices, crew masses) are in LSK-DEC-001.

### Safety concerns

- Rescue in floodwater: life jackets always, crew training, never in moving water, and every trial in calm, shallow water with a safety boat. Safety stops in LSK-BLD-001 section 6 gate standing in the boat, the first launch, boarding trials, load and swamp trials, and rescue use.
- The step hinge has the lowest factor (1.5); it is proof-loaded to twice the working load before any boarding trial.
- Swamped, the transom freeboard is small (36 mm) and two people moving to one side dip the gunwale; until R5 is decided, crews keep people seated, low and centred and move the aft crew amidships.
- The halves weigh 56 and 45 kg; carrying them over rubble or through water is a lifting hazard, so four carriers or the slings are used.

### Recommended next step

Amish decides the five items above. The design looks ready for TRL 4 once he chooses to start it: build the aft half first with the first co-design candidate's boatyard, weigh it, float it alone, and proof-load the step with CalRig before any boarding trial.

## 2026-10-03: photoreal renders

Rendered with Blender Cycles on Amish's Mac from `cad/src/product_model.py`; captioned with `.kit/photo_caption.py`; `media/card.png` and `media/social-preview.png` made with `.kit/cards.py`. Views: hero, exploded, detail. image_qc passes and `render.py --check` has no FAIL.

## 2026-10-03: Amish's requirement decisions carried out

Amish Chadha on 2026-10-03: "i agree with all the 46 recommendations you provided. please proceed." For LaneSkiff these are decisions 30A (open items 1 to 3), 31C (item 4) and 32A (item 5), recorded in `docs/decisions/0003-amish-requirement-decisions.md` (LSK-DDR-003) and moved to Decisions made in `docs/06-design-decisions.md` (LSK-DEC-001 v0.2). Not committed or pushed.

### Changes made and new results

- **30A, light timber specification, five-person rating and a 60 mm wider bottom.** `cad/src/model.py`: bottom 1,060 mm wide at the chine (was 1,000), 4 mm sides; okoume plywood (450 kg/m3), softwood framing (500 kg/m3) and no glass inside the floor in `docs/04-calcs/sizing.py`; rating five persons (375 kg). Results: hull 87.9 kg (was 100.2), halves 49.9 and 38.1 kg (R1 still not met, as accepted with the decision; about 25 and 19 kg a person on the slings); deepest draft 148 mm at the transom and 138 mm forward (R3 met, 2 mm margin; was 187 mm at six persons); beam 1,197 mm (R4 met, 3 mm margin); boarding heel 3.3 deg over the stern step (R6 met). The saving is 12.3 kg, not the 18 kg estimated, because the wider bottom widens the bench foam and the stern quarter foam adds 30 L.
- **31C, stern quarter foam and the aft-crew rule.** Two 15 L foam modules (cores 250 x 190 x 316 mm) in tarpaulin covers, either side of the step opening, standing on the side stringer and bench rail 40 mm forward of the transom (clear of the rail bolt nuts) with 250 mm clear between them, each strapped to the transom ring frame and the side stringer; BOM line 29. Results: swamped trim 0.4 deg stern down, freeboard 161 mm at the transom and 188 mm at the bow with the foam alone; with the rule as well, 216 mm at the transom and 141 mm at the bow (R5 met on paper; was 36 mm). Two people moving 400 mm to one side no longer dip the gunwale (39 mm left).
- **32A, no fin drive.** Nothing in the prototype; R10 restated as not part of the first prototype and stays not shown.
- `docs/03-requirements.md` (LSK-REQ-001 v0.3): rated load five persons; R3, R5 and R10 restated, quoting Amish; statuses updated. `docs/04-calcs/01-sizing.md` (LSK-CAL-001 v0.2), `results.csv`, `docs/02-concept.md` (v0.3), `docs/01-problem.md` (v0.3) and `README.md` updated.
- Constructability: 82 of 82 checks pass (nine added for the quarter modules: seating, straps, 250 mm clear way, clear of the stowed pole). STEP and STL regenerated.

### Cost and mass

Value-engineering target: USD 1,500. Estimated cost of the constructable design: USD 1,961 (USD 461 over the target). The decisions add USD 39: okoume sheets (USD 40 more; okoume about USD 65, 90 and 120 a sheet at 4, 6 and 9 mm, 2026 estimates to confirm), a seventh foam sheet for the wider benches (USD 55) and the quarter modules (USD 30, priced from line 10 foam, tarpaulin and webbing), less softwood framing at about USD 2 a metre (USD 41), glass (USD 21) and epoxy (USD 25). `budget_usd` unchanged. BOM lines 3 and 5 also corrected to the model's 9 mm transom and 6 mm bulkheads.

### Pictures changed

- General arrangement `cad/drawings/LSK-DWG-001` to Rev P3 (beam and bottom width now computed from the model; 4 mm side; quarter foam and five-person notes).
- Concept media regenerated: `media/hero.png`, `media/concept-blueprint.*` (key figures), `media/exploded.png` (quarter modules, BOM 29), `media/cutaway.png`, `media/model.glb`.
- Build plan: `docs/05-build-plan/overview.png` (quarter modules added), every making sketch `LSK-DWG-101` to `114` regenerated with the okoume, softwood and new sizes, new `LSK-DWG-115` (stern quarter module), joints 1 to 8 regenerated and new `joint-09.png`, steps 1 to 17 regenerated (step 10 now fits the quarter modules too). `docs/05-build-plan.md` (LSK-BLD-001 v0.2) text updated, with a new section 3.15.
- Appearance model `cad/src/product_model.py` shows the quarter modules; views exported to `/home/claude/renders/laneskiff` (hero, exploded, detail). The photoreal renders and cards in `media/` predate this change and need re-rendering on Amish's Mac.

### New question for Amish

**R2, payload ratio after the five-person rating.** Proposed, awaiting Amish (LSK-DEC-001, open item 1).
- *State:* the five-person rated load (375 kg) is 4.3 times the 87.9 kg hull, against a target of 6; the hull carries 401 kg within the 150 mm draft (4.6). Cause: the ratio recommended earlier (5.45) assumed six persons on an 83 kg hull, but the five-person rating that meets R3 lowers the load, and the hull came out 5 kg heavier. A ratio of 6 at five persons needs a 62.5 kg hull.
- *Option A, restate R2 as an absolute payload:* "rated load of five persons (375 kg) carried within the R3 draft; the payload ratio is reported, not a pass mark". Met on paper; no design or cost change.
- *Option B, keep the 6 times target:* reported as not met; revisit at TRL 4 once the halves are weighed. No design or cost change.
- *Option C, rate for six persons:* ratio 5.1, still short of 6, and the draft returns to 177 mm (R3 not met).
- **Recommendation: A.** R2 already names an absolute load (about 300 kg); five persons exceed it, and the ratio is better tracked as a figure than a pass mark while the hull is above the carry target.

### Items added to confirm

Okoume bending strength (40 MPa assumed) and floor wear with no inside glass; screw holding in the softwood stringers and inwales and nut plate bearing on the softwood joint frame; the as-built beam (3 mm inside the 1.2 m limit); the R3 margin of 2 mm depends on the timber densities and the 75 kg person mass. BOM line 9 still prices plywood bench boxes (USD 110) that LSK-DDR-002 replaced with covers and straps; worth repricing at the next BOM review.

### Safety

- Rated for five persons, marked on the transom; six put the draft at 177 mm.
- Swamp drill: the aft crew member moves amidships and everyone sits low and centred; the stern foam gives margin when the rule is not followed.
- Thinner sides and softwood framing are softer: the proof loads and trial gates of LSK-BLD-001 section 6 are unchanged and still gate every person carried.

### Recommended next step

Amish decides the R2 question. The design remains ready for TRL 4 when he chooses: build the aft half first, weigh it, check the beam and float it alone, then proof-load the step with CalRig before any boarding trial.

## 2026-10-04: Amish's requirement decisions carried out (round 3)

Amish on 2026-10-04: "For round 3, I agree with all your proposed recommendations". For LaneSkiff this decides open item 1 of LSK-DEC-001 as recommended (6A). Recorded in `docs/decisions/0004-r2-restated.md` (LSK-DDR-004). Wording and records only; no geometry. Not committed or pushed.

### Changes

- `docs/03-requirements.md` v0.4: R2 restated as "payload 375 kg (five persons) within the R3 draft limit; the payload-to-hull ratio is reported"; Amish quoted.
- `docs/04-calcs/01-sizing.md`: summary row and Table 9 caption updated.
- `docs/06-design-decisions.md` v0.3: open item 1 moved to Decisions made; Open decisions now "None."
- No model, BOM, drawing or media change was needed.

### New results

- R2: met on paper as restated: 375 kg at 148 mm draft against the 150 mm limit. Reported ratio 4.3 times hull mass at the rated load (4.6 at 401 kg).
- Cost and mass unchanged.

### For Amish

Nothing new.

## 2026-10-04: photoreal renders redone after the round-2 and round-3 decisions

Views: hero, exploded, detail; cards regenerated; image_qc passes and `render.py --check` has no FAIL.

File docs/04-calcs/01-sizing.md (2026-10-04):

---
doc_id: LSK-CAL-001
title: LaneSkiff sizing calculations
project: LaneSkiff
doc_type: Calculation
version: "0.2"
status: Draft
date: '2026-10-03'
author: Amish Chadha
license: CERN-OHL-S-2.0
revisions:
- version: "0.1"
  date: '2026-10-03'
  author: Amish Chadha
  change: First sizing of the constructable design (LSK-DDR-002); results against LSK-REQ-001
- version: "0.2"
  date: '2026-10-03'
  author: Amish Chadha
  change: Re-run for Amish's decisions 30A, 31C and 32A (LSK-DDR-003); light timber specification, five-person rating, bottom 60 mm wider, 30 L of stern quarter foam and the aft-crew rule; option table replaced by the decided results
---

# LaneSkiff sizing calculations

This revision sizes the design Amish chose on 2026-10-03 (LSK-DDR-003; his words: "i agree with all the 46 recommendations you provided. please proceed."): okoume plywood with 4 mm sides and softwood framing, a five-person rating, a bottom 60 mm wider, 30 L of foam in the stern quarters with the aft-crew rule, and no fin drive in the first prototype. On paper the boat now draws 148 mm at its rated load of five persons (R3 met), floats swamped with 161 mm of freeboard at the transom (R5 met with margin), heels 3.3 degrees when someone boards over the stern step, joins in about six minutes, and fits a 1.2 m lane with 3 mm to spare. The hull weighs 87.9 kg (halves of 49.9 and 38.1 kg), so the carry mass is still not met, as Amish accepted with the decision; and the five-person rated load is 4.3 times the hull mass against a target of 6, which is put to Amish as a new question in `docs/REVIEW.md`.

Every figure comes from `docs/04-calcs/sizing.py`, which imports the parametric model (`cad/src/model.py`), so the sizes here are those of the STEP files, the drawings and the build plan. Tags in square brackets match the script output and `docs/04-calcs/results.csv`. These are screening estimates for a paper proof of concept; they do not replace the load, boarding and swamp trials, which are TRL 4 work.

> **Safety:** These numbers are for a design review, not a rating. No LaneSkiff carries people before its step, straps, handles and bow eye are proof-loaded and it has passed a load test and a swamp test in calm, shallow water with a safety boat and every person in a life jacket. Never in moving water.

## 1. Method and assumptions

**Masses.** Every made part's volume from the model times its material density, plus catalogue masses for bought fittings, plus glass, epoxy, coating and tape worked out from the panel areas and seam lengths.

**Afloat.** The hull envelope (the outside of the planking and the skids) is cut at a trial waterline and the draft found where the displaced water equals the total weight. Trim and heel come from the waterplane, which is a rectangle while the waterline is on the flat part of the bottom: transverse stability GM = KB + I_T / V - KG, and trim = (LCB - LCG) / GM_L.

**Swamped.** Every body floats on its own: the water inside the hull is part of the flood and carries nothing. Foam gives lift for its submerged volume. Plywood, timber and HDPE count as exactly as dense as water, so they give no lift when submerged and their full weight above water (conservative). Glass, epoxy, fittings and foam count at full weight. People count at two thirds of their weight.

*Table 1. Assumptions.*

| # | Assumption | Value | Basis |
| --- | --- | --- | --- |
| A1 | Water density | 1,000 kg/m3 | Fresh floodwater |
| A2 | Marine plywood | Okoume, 450 kg/m3 | Light timber specification (LSK-DDR-003); BS 1088 okoume |
| A3 | Framing and other timber | Softwood framing 500 kg/m3 (ring frames, inwales, stringers, bench rails, knuckle floor); durable hardwood 700 kg/m3 for the step, bow eye pad and rung | Light timber specification; the step and pad keep hardwood for wear and bolt bearing |
| A4 | Foam | Closed-cell polyethylene, 30 kg/m3, under 1 % water uptake by volume | Supplier data to confirm |
| A5 | Glass and epoxy | 0.80 kg/m2 outside the bottom and sides, none inside the floor, 0.20 kg/m2 per coated face, 0.25 kg per metre of taped seam, 1.5 kg of small fixings | Typical stitch-and-glue practice |
| A6 | Persons | 75 kg each; rated load five (a crew of two and three adults, 375 kg); boarder 80 kg | LSK-REQ-001; five-person rating decided by Amish (LSK-DDR-003) |
| A7 | Person positions, rated load | Crew standing aft at 0.4 m (poling) and kneeling forward at 2.9 m; two adults on the aft benches at 1.0 m, one on a forward bench at 2.2 m | Placement for the paper case; trials place people as crews do |
| A8 | Persons when swamped | Two thirds of their weight carried by the boat | Conservative design assumption, to be replaced by the ABYC H-8 procedure test |
| A9 | Material strengths | Plywood bending 40 MPa (glass ignored; okoume to confirm, see LSK-DEC-001); M10 A4-70 bolt 29 kN; nut plate bearing 16 kN; 25 mm webbing 8 kN; strap hinge 4 kN | To confirm with real parts |

## 2. Masses

*Table 2. Hull mass, light timber specification.*

| Tag | Item | Mass |
| --- | --- | --- |
| [M4ply] | Okoume plywood: bottoms, 4 mm sides, transoms, bulkheads, bow box, step decks | 24.8 kg |
| [M4sw] | Softwood framing: ring frames, inwales, stringers, bench rails, knuckle floor | 12.8 kg |
| [M4hw] | Hardwood: hinge rail, backing block, float rim, bow eye pad, rung | 4.2 kg |
| [M4foam] | Foam: bench modules, bow box, stern quarter modules, step float | 18.3 kg |
| [M5] | Glass (outside only), epoxy, coating, tapes, small fixings | 12.4 kg |
| [M4hdpe] | HDPE rub strakes and skids | 4.7 kg |
| [M4fabric] | Bench and quarter module covers and straps | 5.1 kg |
| [M4bought] | Bought fittings: hinges, pad eyes, straps, handles | 4.3 kg |
| [M4steel] | Joint bolts, nut plates, pins, rail bolts, bow eye | 1.3 kg |
| [M1] | **Hull, as carried** | **87.9 kg** |
| [M2], [M3] | Aft half with the stern step; forward half | 49.9 kg; 38.1 kg |
| [M6] | Loose gear (pole, paddles, bow line), not in the hull mass | 6.2 kg |

Plywood areas [M8]: bottom 3.82 m2, sides 2.73 m2, other panels 3.09 m2. Hull centre of mass [M7]: 1,556 mm forward of the transom, 177 mm above the outside of the bottom.

The light specification saves 14.9 kg of timber and 1.2 kg of glass and epoxy against version 0.1 (100.2 kg), but the wider bottom widens the bench modules and the stern quarter modules add 30 L, so foam and covers add 3.9 kg; the net saving is 12.3 kg, less than the 18 kg screening estimate, which left the foam unchanged. Each half carried by two people with the shoulder slings is about 25 and 19 kg a person.

## 3. Afloat

*Table 3. Hydrostatics, fresh water.*

| Tag | Case | Result |
| --- | --- | --- |
| [L1], [L2] | Rated load (five persons); over hull mass | 375 kg; 4.26 |
| [H1] | Draft at rated load, even keel | 143 mm |
| [H2] | Trim at rated load; draft at the transom; at the forward end of the waterline | 0.16 deg stern down; 148 mm; 138 mm |
| [H3] | Lowest freeboard at rated load | 252 mm |
| [H4] | Waterline length and beam at rated load | 3.34 m; 1.10 m |
| [H5] | Transverse GM at rated load, with the aft crew standing | 0.31 m |
| [H6] | Load to sink 10 mm at rated draft | 36.8 kg |
| [H7], [H8] | Load carried at 150 mm draft, even keel; over hull mass | 401 kg; 4.56 |
| [H9] | Draft with the crew of two only | 79 mm |
| [D1] | For comparison, six persons (450 kg) in this design: deepest draft; over hull mass | 177 mm; 5.12 |

With a crew of two the boat draws under 80 mm. At its five-person rated load it draws 148 mm at the transom, inside the 150 mm limit by 2 mm; the wider bottom also doubles the transverse GM at rated load (0.31 m against 0.15 m). Six persons would bring the draft back to 177 mm, so the rating plate says five. The load the hull carries within 150 mm of draft is 401 kg.

## 4. Swamped

*Table 4. Swamped with the rated persons aboard (people at two thirds of their weight).*

| Tag | Quantity | Result |
| --- | --- | --- |
| [F1] | Buoyancy foam in the hull (benches 0.39 m3, bow box 0.17 m3, stern quarter modules 0.03 m3) | 0.592 m3 |
| [F11] | Of which, the two stern quarter modules | 30.0 L |
| [F2] | Water level, inside and out, above the outside of the bottom | 224 mm |
| [F3] | Weight carried by the foam | 307 kg |
| [F4] | Trim, quarter foam fitted, aft crew where they stand | 0.42 deg stern down |
| [F5] | Freeboard at the transom; at the bow | 161 mm; 188 mm |
| [F10] | With the aft-crew rule as well (the aft crew moves amidships): trim; freeboard at the transom; at the bow | 1.19 deg bow down; 216 mm; 141 mm |
| [F6] | Transverse GM, swamped | 0.56 m |
| [F7], [F8] | Two seated persons move 400 mm to one side: heel; low-side freeboard | 13.1 deg; 39 mm (the gunwale stays out) |
| [F9] | Lift needed for zero freeboard as a share of the fitted foam | 0.49 |

The swamped boat floats nearly level with the stern quarter foam alone: 0.4 degrees stern down and 161 mm at the transom, against 36 mm before. The foam gives this margin even when nobody follows the rule. The aft-crew rule adds margin aft but trims the boat 1.2 degrees bow down, so both ends keep at least 141 mm. Fewer persons and wider bench modules also help: two people moving to one side no longer dip the gunwale. Crews still keep people seated, low and centred in a swamped boat.

## 5. Boarding over the stern step

*Table 5. An 80 kg person boarding, crew of two seated amidships (1.6 m on the benches).*

| Tag | Case | Result |
| --- | --- | --- |
| [B1] | Heel with the boarder's weight on the step, 150 mm off the centreline | 3.3 deg |
| [B2] | Trim and transom freeboard while boarding over the stern | 0.7 deg stern down; 279 mm |
| [B3] | For comparison, the same person climbing over the side at the gunwale | 12.8 deg heel |
| [B4] | Low-side freeboard in the side case | 164 mm |

The stern step works as the concept intends: a person climbing over the end of the boat moves its weight a short distance sideways, so the boat barely heels. The same person over the side heels it nearly four times as much and brings the gunwale within 164 mm of the water. The two stern quarter modules leave 250 mm clear between them at the step opening, so the boarder's legs come over the transom between them; their tops (346 mm above the bottom) are a knee rest. The float's own buoyancy (about 17 L) is ignored here, so the real heel and trim while boarding are a little lower.

## 6. Structure

*Table 6. Screening checks of the parts that carry the most load.*

| Tag | Check | Result |
| --- | --- | --- |
| [S1], [S2], [S3] | Floor: largest clear span between stringers and bench rails; bending stress under a 1.2 kN foot load on a 300 mm strip; factor on plywood strength | 160 mm; 26.7 MPa; 1.5 (no glass inside) |
| [S4], [S5] | Joint: boat with rated load hogging over a kerb at the joint, ends free; tension in each top bolt; factor on the bolt and on the nut plate bearing | 2.7 kN; 10.7 and 5.9 |
| [S6], [S7] | Step: 80 kg kneeling on the aft edge of the float at its stop, dynamic factor 2; pull in each stop strap; factor on the webbing | 1.88 kN; 4.2 |
| [S8] | Step hinges: load on each (upper bound) and factor | 2.67 kN; 1.5 |

The floor needs its centre stringer and the bench rails: with only two stringers the span would be 255 mm and the factor under 1. The floor check never counted the inside glass, so leaving it out does not change the factor; it does leave the floor with less abrasion margin, and the 40 MPa bending strength is to be confirmed for the okoume actually bought. The nut plates bear on softwood now; the factor of 5.9 uses the 10 MPa bearing figure, which softwood across the grain may not reach, so the plates are checked in the joint proof load. The step hinges have the smallest factor; heavy hinges with 6 mm pins are specified and the hinge is proof-loaded before any boarding trial (LSK-BLD-001, safety stops).

## 7. Joining the halves

[T1] Placing and aligning the halves on the two pins takes about 2 minutes, eight bolts at about 25 seconds each with one 17 mm spanner about 3.2 minutes, and a final check about 1 minute: about 6.2 minutes for two people (estimate). The nuts are welded to plates on the aft frame, so nobody needs to hold a second spanner inside the boat.

## 8. Material substitution table

*Table 7. Build paths, same hull form (R8).*

| Tag | Build path | Hull mass | Load at 150 mm draft | Load over hull mass |
| --- | --- | --- | --- | --- |
| [P1] | Okoume plywood and epoxy, stitch and glue, softwood framing (prototype) | 88 kg | 401 kg | 4.6 |
| [P2] | Aluminium 5052 sheet: 2.5 mm bottom, 2.0 mm sides and ends, welded or riveted; aluminium angle frames | 101 kg | 388 kg | 3.8 |
| [P3] | HDPE or polypropylene sheet: 8 mm bottom, 6 mm sides, 5 mm ends, plastic welded | 111 kg | 377 kg | 3.4 |

The plywood path is now the lightest; the other two come out close to each other, because the foam, step, fittings and framing weigh the same in each. Aluminium needs welding or riveting skills and corrosion care; plastic sheet needs a plastic welder and is the heaviest but the most abrasion-tolerant. Plywood and epoxy is the path most yards in Kerala and Bihar can build and repair.

## 9. Results of Amish's decisions of 2026-10-03

*Table 8. What decisions 30A, 31C and 32A changed (LSK-DDR-003).*

| Decision | Change | Result |
| --- | --- | --- |
| 30A | Okoume plywood, 4 mm sides, softwood framing, no glass inside the floor; five-person rating; bottom 60 mm wider (1,060 mm at the chine) | Hull 87.9 kg (was 100.2), halves 49.9 and 38.1 kg; deepest draft 148 mm at five persons (was 187 mm at six); beam 1,197 mm |
| 31C | Two 15 L foam modules in the stern quarters, and the aft-crew rule | Swamped transom freeboard 161 mm with the foam alone, 216 mm with the rule as well (was 36 mm) |
| 32A | No fin drive in the first prototype | Nothing to compute; R10 stays not shown |

*Table 9. Figures behind the R2 restatement (decision 6A of 2026-10-04, LSK-DDR-004; ratio reported, not a pass mark).*

| Tag | Quantity | Result |
| --- | --- | --- |
| [L2] | Five-person rated load over hull mass | 4.26 |
| [D3] | Load carried at 150 mm draft over hull mass | 4.56 |
| [D2] | Hull mass at which the five-person load would be 6 times hull mass | 62.5 kg |
| [D1] | Six persons over hull mass (but 177 mm draft) | 5.12 |

## 10. Cost

[C1] Value-engineering target: USD 1,500. Estimated cost of the constructable design: USD 1,961 (USD 461 over the target), from `bom/bom.csv`. The decisions added USD 39: okoume plywood (USD 40 more across the five sheet lines), one more foam sheet for the wider benches (USD 55) and the two stern quarter modules (USD 30), less softwood framing (USD 41), glass (USD 21) and epoxy (USD 25). The largest lines are the foam (USD 385), the 6 mm okoume (USD 270 for three sheets), the epoxy (USD 175) and the fittings (handles USD 100, step USD 75).

## 11. Results against the requirements

*Table 10. Results against LSK-REQ-001 (version 0.3).*

| ID | Result | Status |
| --- | --- | --- |
| R1 | Hull 87.9 kg; halves 49.9 and 38.1 kg | Not met (accepted with decision 30A) |
| R2 | 375 kg five-person rated load is 4.3 times hull mass; 401 kg within 150 mm draft (4.6) | Met as restated (ratio reported) |
| R3 | 148 mm at the transom, 138 mm at the forward end of the waterline (five persons) | Met on paper |
| R4 | 1,197 mm over the rub strakes | Met (3 mm margin) |
| R5 | Afloat, 0.4 deg trim, 161 mm freeboard at the transom; 216 mm with the aft-crew rule | Met on paper |
| R6 | 3.3 deg over the stern step | Met on paper |
| R7 | About 6 min, one spanner | Met on paper (estimate) |
| R8 | Three build paths with mass and payload | Met on paper |
| R9 | USD 1,961 | Over the value-engineering target by USD 461 |
| R10 | No fin drive in the first prototype (decision 32A) | Not shown on paper |

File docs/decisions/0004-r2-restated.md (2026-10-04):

---
doc_id: LSK-DDR-004
title: LaneSkiff R2 restated
project: LaneSkiff
doc_type: Design decision record
version: "0.1"
status: Draft
date: '2026-10-04'
author: Amish Chadha
license: CERN-OHL-S-2.0
revisions:
- version: "0.1"
  date: '2026-10-04'
  author: Amish Chadha
  change: Amish's round-3 decision 6A recorded; R2 restated
---

# 0004: R2 restated

- **Date:** 2026-10-04
- **Status:** accepted. Decided by Amish on 2026-10-04: "For round 3, I agree with all your proposed recommendations". For LaneSkiff this accepts option A of open item 1 in LSK-DEC-001 (portfolio item 6A).

## Context

After the five-person rating (30A) the 375 kg rated load is 4.3 times the 87.9 kg hull, against R2's scaffold target of 6 times hull mass. The hull is above the carry target, so the ratio cannot reach 6 on this build path.

## Options considered

A: restate R2 as an absolute payload with the ratio reported, not a pass mark. B: keep the 6 times target as unmet and revisit at TRL 4. C: rating changes (see `docs/REVIEW.md`). Recommendation was A.

## Decision

R2 is restated as "payload 375 kg (five persons) within the R3 draft limit; the payload-to-hull ratio is reported". Result: met on paper, 375 kg at 148 mm draft; ratio 4.3 at the rated load (4.6 at 401 kg and 150 mm), reported.

## Consequences

Requirements text, calculation note wording and registers only. No geometry, bill of materials or cost change; value-engineering figures in the register are unchanged.

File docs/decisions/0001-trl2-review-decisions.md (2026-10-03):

---
doc_id: LSK-DDR-001
title: LaneSkiff TRL 2 review decisions
project: LaneSkiff
doc_type: Design decision record
version: "0.1"
status: Draft
date: '2026-10-03'
author: Amish Chadha
license: CERN-OHL-S-2.0
revisions:
- version: "0.1"
  date: '2026-10-03'
  author: Amish Chadha
  change: TRL 2 review items decided under Amish's 2026-10-03 pre-approvals
---

# 0001: TRL 2 review decisions

- **Date:** 2026-10-03
- **Status:** decided. Decided by Amish under his pre-approval of 2026-10-03: "start with the first 14 repos from the list of 29 projects. I pre-approve the batch runs along with any recommendations you come up with. I also accept any cost overruns or variations from the assumed scope cost." and, for this batch, "Proceed with the remaining 15 scaffolds".
- **Not decided here:** requirements that are not met or at risk on paper (R1, R2, R3, R5, R10). Those are set out with options for Amish in `docs/REVIEW.md` and listed as open decisions in LSK-DEC-001.

## Context

The scaffold (LSK-PRB-001, LSK-PRC-001 and LSK-REQ-001, all v0.1) described a flat-bottomed skiff of about 3.5 by 1.2 m in two rigid halves bolted at a mid bulkhead, with buoyancy under side benches and at the ends, a hinged buoyant step at the stern centre, carry handles and yoke points, rub strakes and skids, an optional fin drive and a material substitution table. It left five open questions: the build material, the step depth and folding, level flotation inside the weight budget, the fin drive, and the trial partner. Populating the concept to TRL 2 meant settling the concept choices below. Items that touch safety take the conservative option and say what evidence would relax it. Partners and regions are the first candidates to approach, not agreements.

## Options considered

*Table 1. Options.*

| # | Item | Options |
| --- | --- | --- |
| D1 | Hull form | (a) jon boat with a narrow bow transom; (b) punt form, constant width, flat bottom raked at the bow, flat flared sides; (c) round-bilge skiff |
| D2 | The split | (a) one mid bulkhead shared by both halves; (b) each half closed by its own bulkhead, bolted face to face |
| D3 | First build path | (a) plywood and epoxy, stitch and glue; (b) aluminium sheet; (c) HDPE sheet |
| D4 | Buoyancy layout and accounting | (a) foam low under the floor; (b) LevelHull layout: outboard along the sides and in a bow box, no lift credited to the timber, persons at two thirds when swamped |
| D5 | Boarding step | (a) rigid ladder; (b) floating step on a hinge, kick rung below, transom handholds |
| D6 | Load case for the calculations | (a) 300 kg; (b) six persons, a crew of two and four adults, 450 kg |
| D7 | Shoulder yoke points | (a) separate yoke fittings; (b) padded slings clipped to the carry handles |
| D8 | Propulsion stowage | (a) one-piece 3 m pole; (b) two 1.5 m sections that stow inside a half |
| D9 | Co-design candidates | First candidates to approach |
| D10 | Requirement targets | (a) revise; (b) keep the TRL 1 targets unchanged and report against them |

## Decisions

- **D1: (b) punt form.** Constant width gives the widest waterline for a lane-width beam and the lowest draft, and every panel is flat. Bottom 1.0 m wide at the chine, flat for 2.7 m, raked to 200 mm at the bow; sides 400 mm, flared 8 degrees; 3.6 m long.
- **D2: (b) two closed halves.** Each half floats on its own and the joint carries load but needs no seal; it keeps the bolt-together design-around clear of folding or flexible hulls.
- **D3: (a) plywood and epoxy** for the first prototype; aluminium and HDPE paths documented at concept level in the material substitution table (meets the intent of R8 on paper).
- **D4: (b) LevelHull layout,** with conservative accounting: plywood and timber give no lift when submerged; people count at two thirds of their weight when swamped. Relaxed only by an ABYC H-8 procedure swamp test.
- **D5: (b) floating step** after the expired US6932020B2 form: a buoyant float hinged to a rail on the transom, a kick rung 270 mm below it on webbing, two transom grab handles. Conservative safety choices: a 40 mm gap between float and rail so nothing can be trapped through the swing, stop straps at 20 degrees below level, and a proof load to twice the working load before any boarding trial. A smaller gap would need a pinch test with a test finger to justify it.
- **D6: (b) six persons, 450 kg,** for the calculations, reading "four adults plus crew" literally. The rating of the first prototype is part of the R3 decision for Amish.
- **D7: (b) padded slings** clipped to the two carry handles at one end of a half; no separate yoke fittings.
- **D8: (b) two 1.5 m sections** joined by an internal sleeve.
- **D9: first candidates to approach,** none approached yet: a fishers' volunteer rescue group in Malappuram district, Kerala, with a nearby plywood-and-epoxy boatyard; country boat makers in a flood-prone district of north Bihar; a state disaster response force or civil defence training unit for trials.
- **D10: (b) targets unchanged.** Requirements not met are reported and put to Amish with options; the cost requirement is reported against the value-engineering target (STANDARDS section 18).
- Pitch, problem, design-arounds and `budget_usd` unchanged.

## Consequences

- The constructable design (LSK-DDR-002) follows from D1 to D8.
- With D3 and D4 the hull comes out at 100 kg, which leaves R1 and R2 unmet; with D6 the draft misses R3. These are for Amish.

## Safety

> **Safety:** D4 and D5 are safety choices and take the conservative option. Flotation and a stable step do not make flood rescue safe: life jackets, training, a safety boat for trials, and no moving water remain the rules in every document.

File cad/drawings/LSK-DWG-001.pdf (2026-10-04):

CONCEPT, NOT FOR FABRICATION | LaneSkiff · github.com/BoujeeEnjinia1701/laneskiff

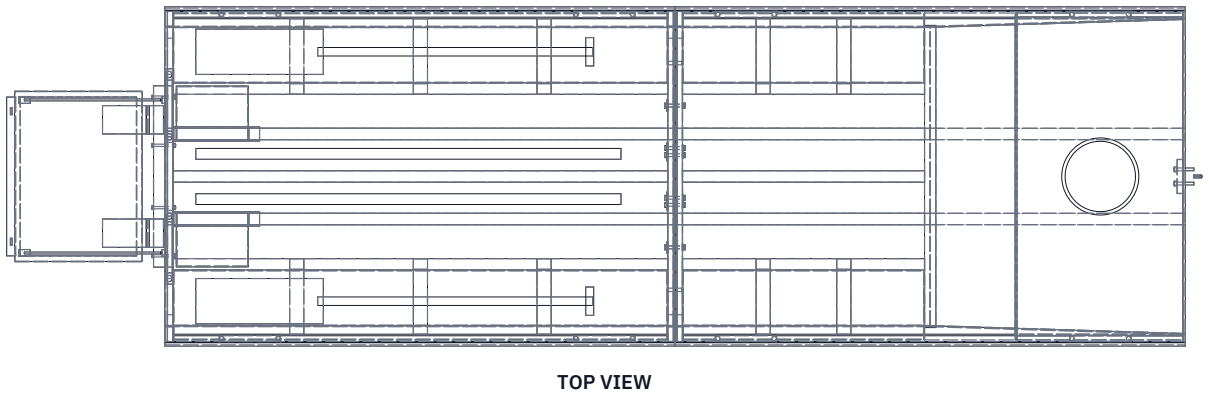
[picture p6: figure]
TOP VIEW
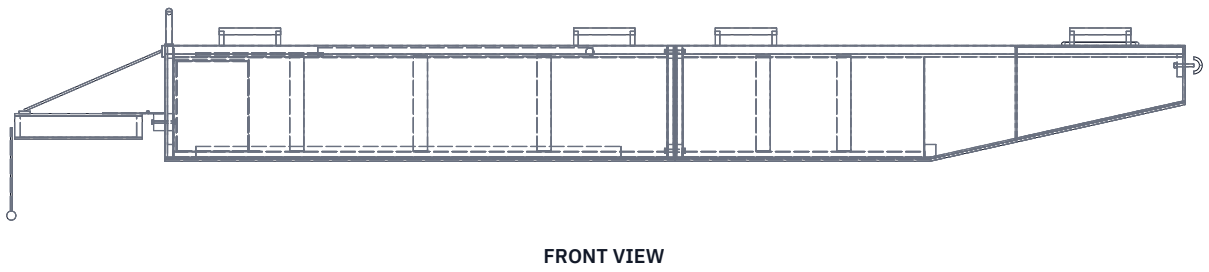
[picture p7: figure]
FRONT VIEW

Scale 1:25; looking at the front (along +Y)

Scale 1:25; looking down (along -Z)

RIGHT VIEW
Scale 1:25; looking at the right side (along -X)

4218

1197 747

SECTION A-A
Scale 1:10; looking aft (along -X), 1.0 m forward of the transom

FOAM MODULE IN COVER (9, 10)

INWALE (7)

RUB STRAKE (12)

SIDE 4 PLY (2)

BENCH RAIL (9)

STRINGER (8)

SKID (13)

BOTTOM 6 PLY (1)

MAIN SIZES AND FIGURES (MM UNLESS STATED)
Length 3,600 in two halves of 1,800; beam overall 1,197 Depth 400; bottom 1,060 wide at the chine; sides flared 8 deg Bottom flat to 2,700 from the transom, raked to 200 at the bow Each half closed by its own bulkhead; joint: 8 M10 x 80 bolts Bench modules 330 from the centreline to the side, top 360 Stern step float 450 x 600 x 90, hinged 40 behind the rail
Kick rung 270 below the float; stop straps at 20 deg down Stern quarter foam 2 x 15 L, 250 clear way between (29) Rated load 5 persons (375 kg); see LSK-CAL-001 for drafts Third-angle; X from transom, Y to port; (n) = BOM line
REV | DESCRIPTION | DATE | BY
P1 | Preliminary GA for TRL 3 (from cad/src/model.py) | 2026-10-03 | AC
P2 | LSK-DDR-002: design for construction | 2026-10-03 | AC
P3 | LSK-DDR-003: light timber, bottom 60 wider, 4 mm sides, stern quarter foam | 2026-10-03 | AC
LANESKIFF | github.com/BoujeeEnjinia1701/laneskiff

## Two-piece flood rescue skiff: general arrangement

DRAWING NO.
LSK-DWG-001

REV
P3

SHEET
1 of 1

SIZE

## ANSI B

SCALE
1:25

UNITS
mm
PROJECTION | DATE
2026-10-03

DRAWN
Amish Chadha

MATERIAL / NOTES
Okoume plywood, softwood framing and epoxy; parts per bom/bom.csv. PRELIMINARY, NOT FOR FABRICATION
Licensed CERN-OHL-S-2.0 · Design Molecule Lab · designmolecule.com | Generated from cad/src; do not edit by hand

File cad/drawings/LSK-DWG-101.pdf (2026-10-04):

### BUILD PLAN SKETCH, PLAN NOT YET BUILT LaneSkiff · github.com/BoujeeEnjinia1701/laneskiff

FRONT VIEW
Scale 1:25; looking at the front (along +Y)

TOP VIEW
Scale 1:25; looking down (along -Z)

RIGHT VIEW
Scale 1:25; looking at the right side (along -X)

3600

1110 206

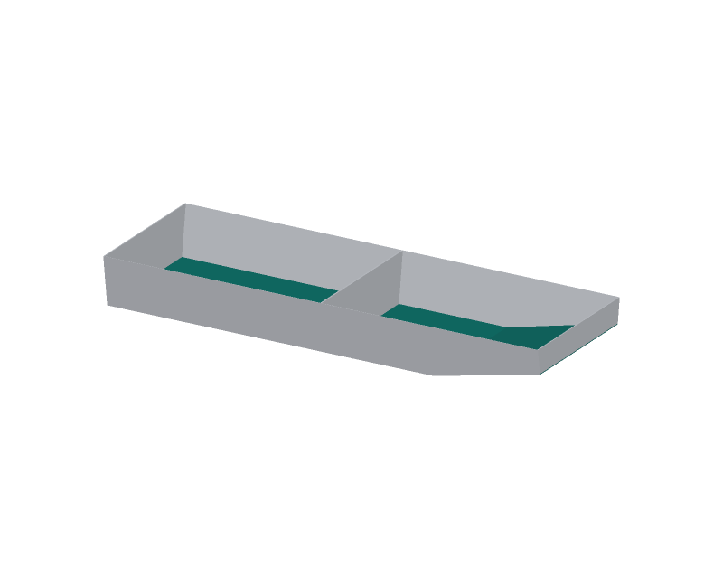
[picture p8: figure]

WHERE IT GOES
This part in colour, its neighbours in grey

HOW TO MAKE IT AND HOW IT FITS
Aft bottom 1,800 x 1,052; forward flat 900 x 1,052; bow rake panel 921 long, 1,052 wide aft to 1,108 at the bow.
Mark the centreline and the stringer lines 150 each side.
Long edges are straight; they butt the inside of the side panels. Drill 2 mm stitch holes 12 in from the edges every 150.
Bow rake: aft edge square, forward edge bevelled 12.5 deg to sit under the bow transom.
Seal both faces with epoxy; no glass inside the floor.
REV | DESCRIPTION | DATE | BY
P1 | Making sketch for the prototype build plan | 2026-10-03 | AC
LANESKIFF | github.com/BoujeeEnjinia1701/laneskiff

## Bottom panels (aft, forward flat, bow rake)

DRAWING NO.
LSK-DWG-101

REV
P1

SHEET
1 of 1

SIZE

## ANSI B

SCALE
1:25

UNITS
mm
PROJECTION | DATE
2026-10-03

DRAWN
Amish Chadha

MATERIAL / NOTES
6 mm okoume marine plywood, glass outside only
Licensed CERN-OHL-S-2.0 · Design Molecule Lab · designmolecule.com | Generated from cad/src; do not edit by hand

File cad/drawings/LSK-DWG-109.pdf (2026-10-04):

### BUILD PLAN SKETCH, PLAN NOT YET BUILT LaneSkiff · github.com/BoujeeEnjinia1701/laneskiff

FRONT VIEW
Scale 1:10; looking at the front (along +Y)

TOP VIEW
Scale 1:10; looking down (along -Z)

RIGHT VIEW
Scale 1:10; looking at the right side (along -X)

1745

287 356

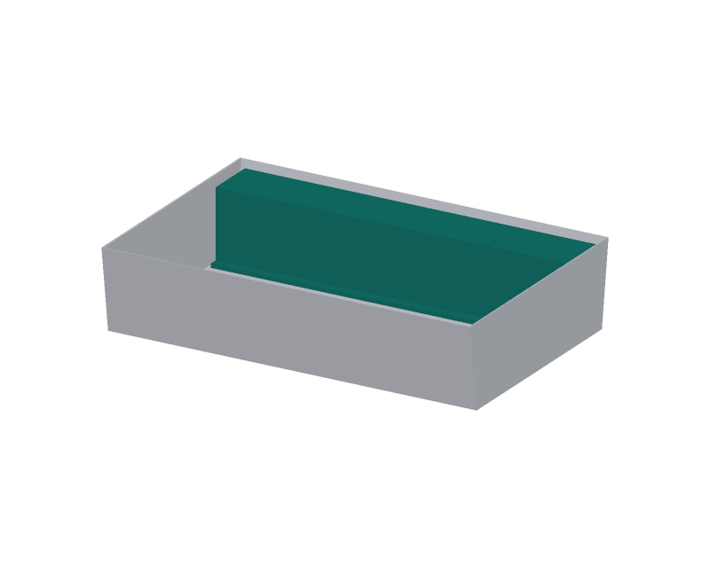
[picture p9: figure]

WHERE IT GOES
This part in colour, its neighbours in grey

HOW TO MAKE IT AND HOW IT FITS
Foam core: 50 layers stacked to 350, outboard edge bevelled 8 deg; 1,741 long aft, 850 long forward; 193 to 242 wide. Cover: sewn sleeve, laced ends; same as LevelHull modules. Rail 40 x 20 softwood glued and screwed to the floor along the module's inboard foot, 330 from the centreline.
Straps 50 webbing (three aft, two forward): screwed to the inwale's inner face, over the module, down to the rail. Module top touches the underside of the inwale.
REV | DESCRIPTION | DATE | BY
P1 | Making sketch for the prototype build plan | 2026-10-03 | AC
LANESKIFF | github.com/BoujeeEnjinia1701/laneskiff

## Bench module (four)

DRAWING NO.
LSK-DWG-109

REV
P1

SHEET
1 of 1

SIZE

## ANSI B

SCALE
1:10

UNITS
mm
PROJECTION | DATE
2026-10-03

DRAWN
Amish Chadha

MATERIAL / NOTES
PE foam 50 mm layers, PVC tarpaulin 650 g/m2, softwood rail, webbing
Licensed CERN-OHL-S-2.0 · Design Molecule Lab · designmolecule.com | Generated from cad/src; do not edit by hand

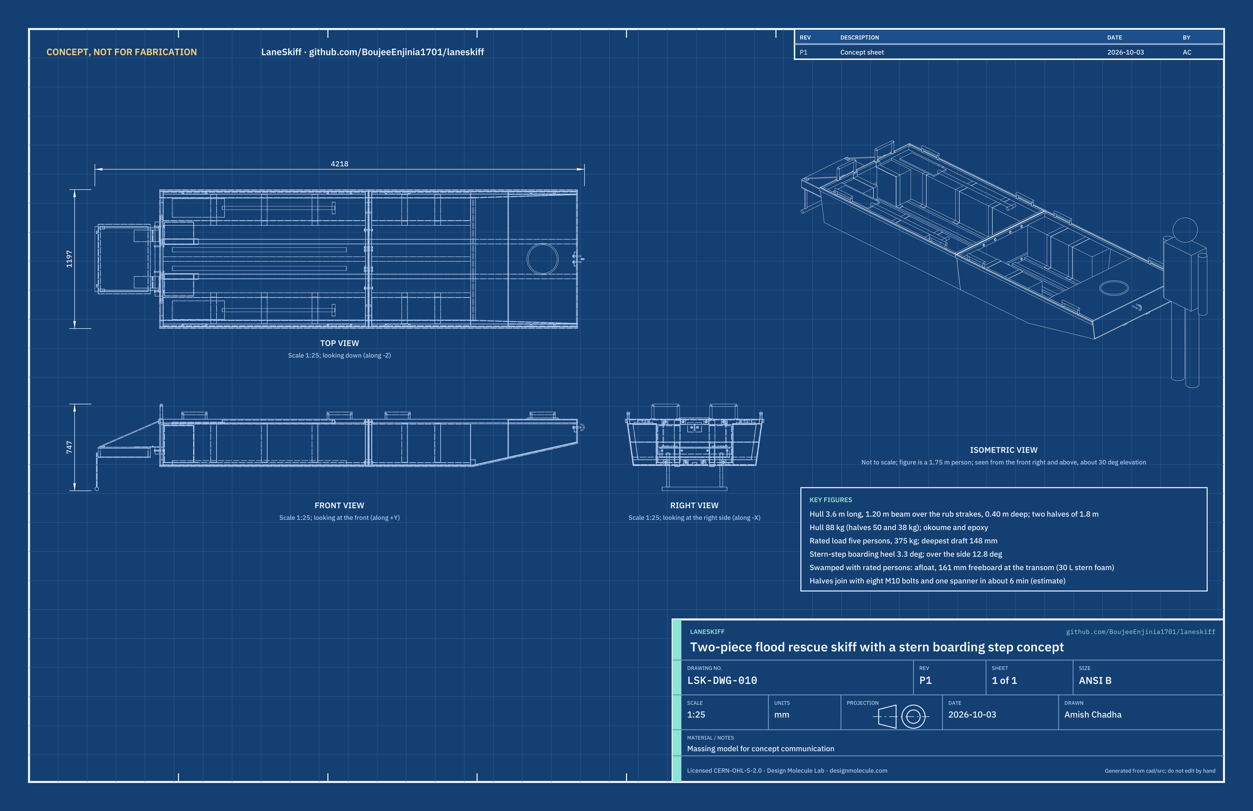
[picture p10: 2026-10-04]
media/concept-blueprint.png

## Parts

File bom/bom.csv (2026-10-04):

line | item | qty | spec | supplier | unit_cost_usd | make_buy | notes
1 | Bottom panels | 2 | Okoume marine plywood (BS 1088) 6 mm, 1220 x 2440 mm sheet; cut to the aft bottom (1800 x 1052) on one sheet, the forward flat bottom (900 x 1052) and bow rake panel (921 x 1052 to 1108) on the other | Plywood dealer or boatyard | 90.00 | Make | Light timber specification (LSK-DDR-003); glass cloth outside only (line 23), none inside the floor; offcut gives the bow deck. Price basis: okoume 6 mm sheet from an Indian plywood importer, about USD 90 (2026 estimate, to confirm)
2 | Side panels | 2 | Okoume marine plywood (BS 1088) 4 mm, 1220 x 2440 mm sheet; four panels 1800 long, 400 high aft, forward panels cut to the bow rake | Plywood dealer or boatyard | 65.00 | Make | Two panels per sheet; 4 mm sides (LSK-DDR-003). Price basis: okoume 4 mm sheet, about USD 65 (2026 estimate, to confirm)
3 | Stern transom and 9 mm parts | 1 | Okoume marine plywood (BS 1088) 9 mm, 1220 x 2440 mm sheet; stern transom 1054 to 1164 wide x 394 high, bow transom (line 4) and step float top deck 600 x 450 | Plywood dealer or boatyard | 98.00 | Make | Sheet about USD 120 (okoume 9 mm, 2026 estimate, to confirm), shared with line 4; offcut kept for repairs
4 | Bow transom | 1 | Share of the line 3 sheet; about 1109 wide at the bottom edge to 1164 at the top x about 196 high, bottom edge bevelled to the rake | Cut from the line 3 sheet | 22.00 | Make | Cost is the share of the line 3 sheet
5 | Joint bulkheads and 6 mm parts | 1 | Okoume marine plywood (BS 1088) 6 mm, 1220 x 2440 mm sheet; two bulkheads 1054 to 1164 wide x 394 high, bow box wall, step float bottom deck | Plywood dealer or boatyard | 90.00 | Make | Price basis as line 1. Corrected to 6 mm to match the model and LSK-DDR-002 C9 (the line said 9 mm)
6 | Ring frames | 9 | Softwood (pine, fir or similar, about 500 kg/m3, kiln dried, clear grade) 20 x 45 mm, per metre; three rings of four members (transom and the two joint bulkheads), half-lapped at the corners | Timber yard | 2.00 | Make | About 8.4 m used; Softwood framing (LSK-DDR-003). Price basis: clear softwood about USD 2 per metre at this section (2026 estimate, to confirm)
7 | Inwales | 8 | Softwood (pine, fir or similar, about 500 kg/m3, kiln dried, clear grade) 20 x 40 mm, per metre; four lengths of about 1.74 to 1.76 m | Timber yard | 2.00 | Make | Carry handles bolt through them; Softwood framing (LSK-DDR-003). Price basis: clear softwood about USD 2 per metre at this section (2026 estimate, to confirm)
8 | Stringers and knuckle floor | 10 | Softwood (pine, fir or similar, about 500 kg/m3, kiln dried, clear grade) 45 x 20 mm, per metre; six stringers (three per half) and the knuckle floor 40 x 45 across the boat | Timber yard | 2.00 | Make | Skid screws go into the side stringers; Softwood framing (LSK-DDR-003). Price basis: clear softwood about USD 2 per metre at this section (2026 estimate, to confirm)
9 | Bench boxes | 2 | Marine plywood 4 mm, 1220 x 2440 mm sheet; four bench boxes (face, top, two end caps); bow box wall and deck from 6 mm offcuts | Plywood dealer | 55.00 | Make | Every face sealed with epoxy before the foam goes in
10 | Buoyancy foam | 7 | Closed-cell polyethylene foam sheet 2000 x 1000 x 50 mm, about 30 kg/m3, water absorption under 1 % by volume (supplier data to confirm); not polystyrene, not open-cell polyurethane | Packaging foam or fishing float supplier | 55.00 | Buy | 0.61 m3 net: benches 0.39, bow box 0.17, step float 0.02; the stern quarter modules are line 29. One more sheet than before because the 60 mm wider bottom widens the bench modules (LSK-DDR-003); cut in 50 mm layers, no glue needed
11 | Joint bolts and nut plates | 8 | M10 x 80 hex bolt, stainless A4-70, with a 30 mm washer; nut plate 40 x 40 x 3 mm galvanised steel with an M10 nut welded on, two 4 x 20 screws; plus two 12 mm stainless alignment pins (one per four bolts) | Fastener supplier and local welder | 5.00 | Buy | One 17 mm spanner joins the halves
12 | Rub strakes | 8 | HDPE strip 15 x 40 mm, per metre; four lengths of 1800 mm | Plastics supplier | 4.00 | Buy | Screwed through the side into the inwale every 200 mm
13 | Bottom skids | 8 | HDPE strip 60 x 10 mm, per metre; two per half, forward pair bent over the knuckle | Plastics supplier | 4.00 | Buy | Stainless 5 x 30 screws into the side stringers every 150 mm
14 | Stern step | 1 | Hinge rail 40 x 60 x 640 hardwood and transom backing block 20 x 60 x 640; four M8 x 90 stainless bolts; float rim 20 mm hardwood, 9 mm top deck (line 5), 6 mm bottom deck (offcut), foam core (line 10); two heavy stainless strap hinges 100 mm wide; 3 mm rubber flap over the hinge gap; non-slip coating on the deck | Hardware store and timber yard | 75.00 | Make | Float 450 x 600 x 90 mm
15 | Step stop straps and pad eyes | 1 | Two 25 mm polyester webbing straps, breaking strength at least 8 kN (to confirm), sewn loops; four stainless pad eyes with bolts | Marine hardware supplier | 25.00 | Buy | Stop the step 20 deg below level
16 | Kick rung | 1 | Hardwood or aluminium rung 32 mm diameter x 560 mm on two 25 mm webbing straps, hung 270 mm below the step | Timber yard and webbing supplier | 12.00 | Make | Rolls up on the step for carrying
17 | Transom grab handles | 2 | Stainless steel tube grab handle about 250 mm long, 25 mm tube, bolted through the transom top and ring frame | Marine hardware supplier | 18.00 | Buy | Handholds for boarding; also stern carry handles
18 | Carry handles | 8 | Grab handle about 200 mm long, glass-filled nylon or stainless, two M6 bolts through the inwale | Marine hardware supplier | 8.00 | Buy | Two at each end of each half
19 | Push pole | 1 | Two 1.5 m sections of aluminium tube 38 x 1.6 mm with an internal joining sleeve and pin; hardwood fork foot and rubber end cap | Aluminium stockist | 45.00 | Make | Each section stows inside the aft half
20 | Paddles | 2 | Paddle about 1.4 m, aluminium shaft, plastic blade | Market or outdoor store | 30.00 | Buy | Stowed on the aft bench tops
21 | Bow eye and bow line | 1 | Stainless U-bolt M8 with backing plate and nuts through the bow transom and a hardwood pad 20 x 120 x 80; 10 m of 10 mm polyester rope | Marine hardware supplier | 22.00 | Buy | Tow and doorway holding line
22 | Epoxy resin and hardener | 7 | Laminating epoxy, per kg, with slow hardener | Boatbuilding supplier | 25.00 | Buy | Stitch-and-glue fillets, glass outside, two coats on every plywood face; 1 kg less than before with no glass inside the floor (LSK-DDR-003)
23 | Glass cloth | 7 | Woven glass cloth 400 g/m2 on the outside of the bottom and sides, per square metre (about 6.6 m2 plus laps) | Boatbuilding supplier | 7.00 | Buy | No glass inside the floor (light timber specification, LSK-DDR-003)
24 | Glass tape | 30 | Glass tape 100 mm wide, per metre | Boatbuilding supplier | 1.00 | Buy | Chines and end seams inside and out
25 | Building consumables | 1 | Copper stitching wire or cable ties, wood flour and silica fillers, sandpaper, brushes, rollers, gloves | Hardware store | 50.00 | Buy
26 | Topcoat | 2 | Exterior polyurethane or marine enamel, per litre; high-visibility orange topsides, white inside | Hardware store | 20.00 | Buy | Epoxy needs a UV-resistant topcoat
27 | Screws and sealant | 1 | Stainless screws for strakes, skids, handles and benches; polyurethane sealant for every hole below the sheer | Fastener supplier | 45.00 | Buy
28 | Shoulder carry slings | 2 | Padded 50 mm webbing sling with two snap hooks, clipped to the two handles at one end of a half | Webbing supplier | 15.00 | Buy | Takes the half's weight onto the carriers' shoulders
29 | Stern quarter foam modules | 2 | Foam core 250 x 190 x 316 mm (15 L) cut from closed-cell PE foam as line 10 (six 50 mm layers and one 16 mm layer); sewn PVC-coated polyester tarpaulin sleeve 650 g/m2 with laced ends; one 50 mm webbing strap with four stainless screws and penny washers | Foam supplier, sail or tarpaulin maker, webbing supplier | 15.00 | Make | Either side of the step opening, 250 mm clear between them (LSK-DDR-003). Price basis: foam 0.015 m3 at line 10 rates (about USD 8), 0.4 m2 of tarpaulin with sewing (about USD 5), 1 m of webbing and screws (about USD 2)

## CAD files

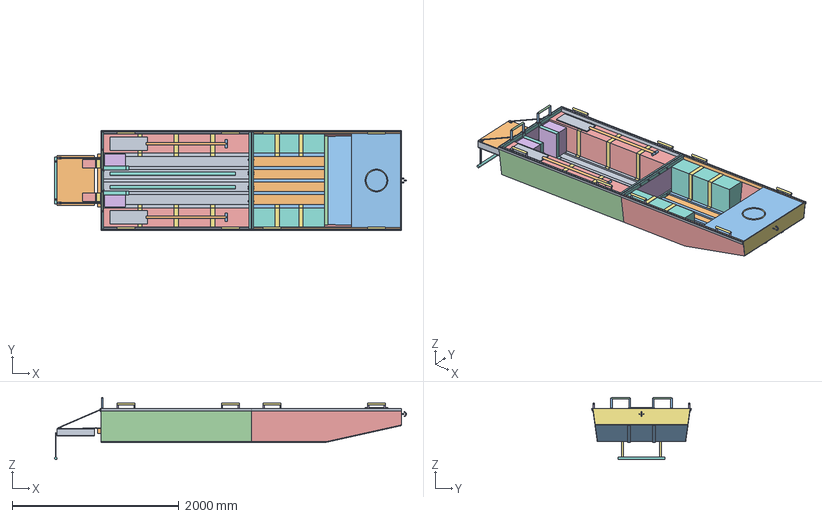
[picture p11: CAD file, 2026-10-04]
cad/step/laneskiff-assembly.step
4218.0 x 1196.7 x 747.0 mm

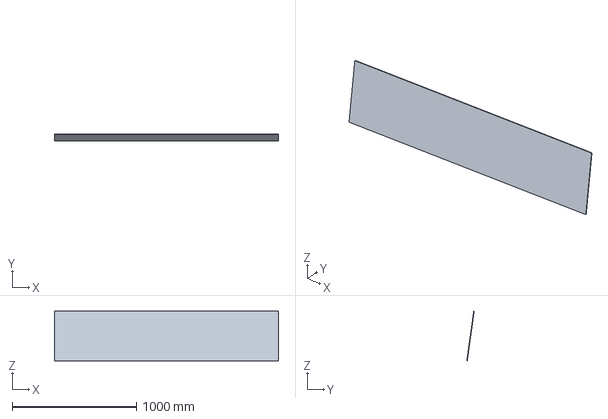
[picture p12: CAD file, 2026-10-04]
cad/step/panel-side-aft-port.step
1800.0 x 60.3 x 400.0 mm

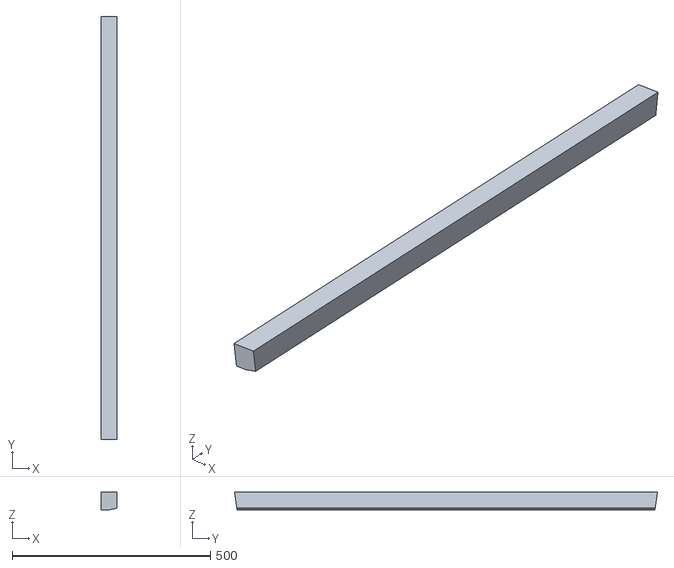
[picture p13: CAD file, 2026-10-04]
cad/stl/knuckle-floor.stl
40.0 x 1066.3 x 45.0

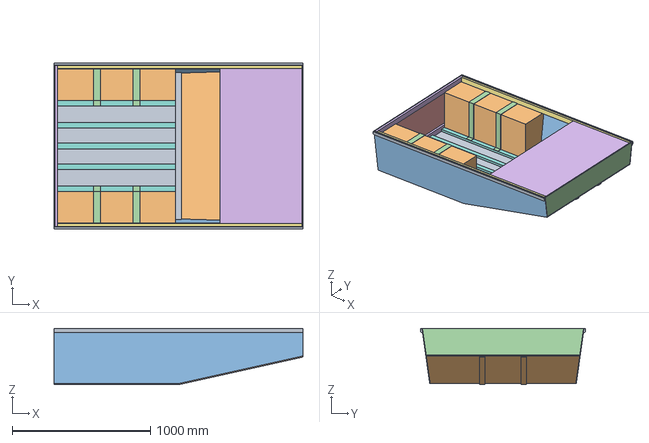
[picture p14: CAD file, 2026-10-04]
cad/step/laneskiff-forward-half.step
1800.0 x 1196.7 x 408.0 mm

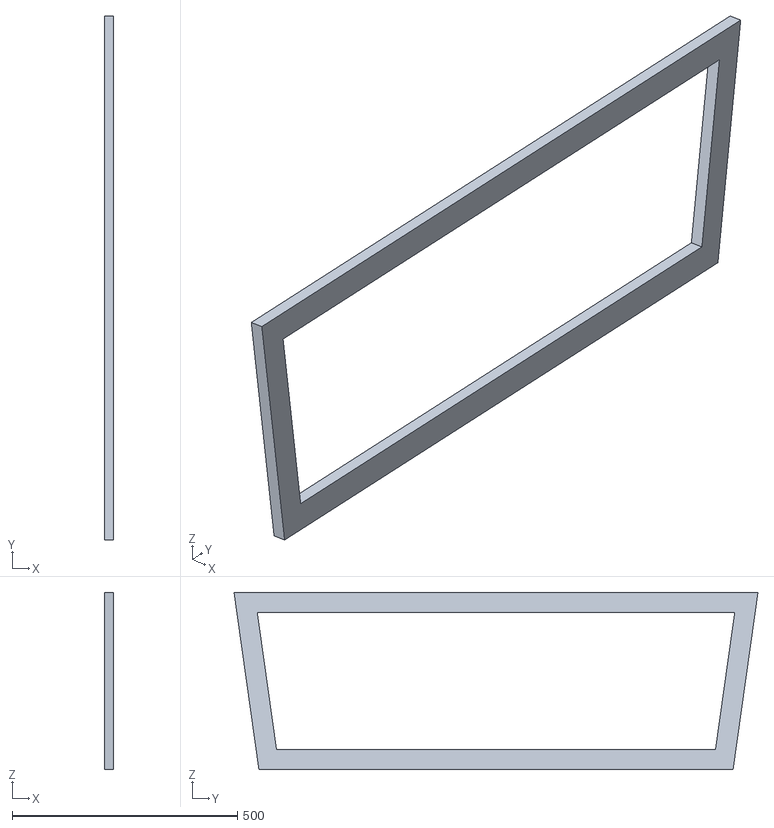
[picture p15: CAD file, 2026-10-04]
cad/stl/ring-frame-joint-aft.stl
20.0 x 1164.4 x 394.0

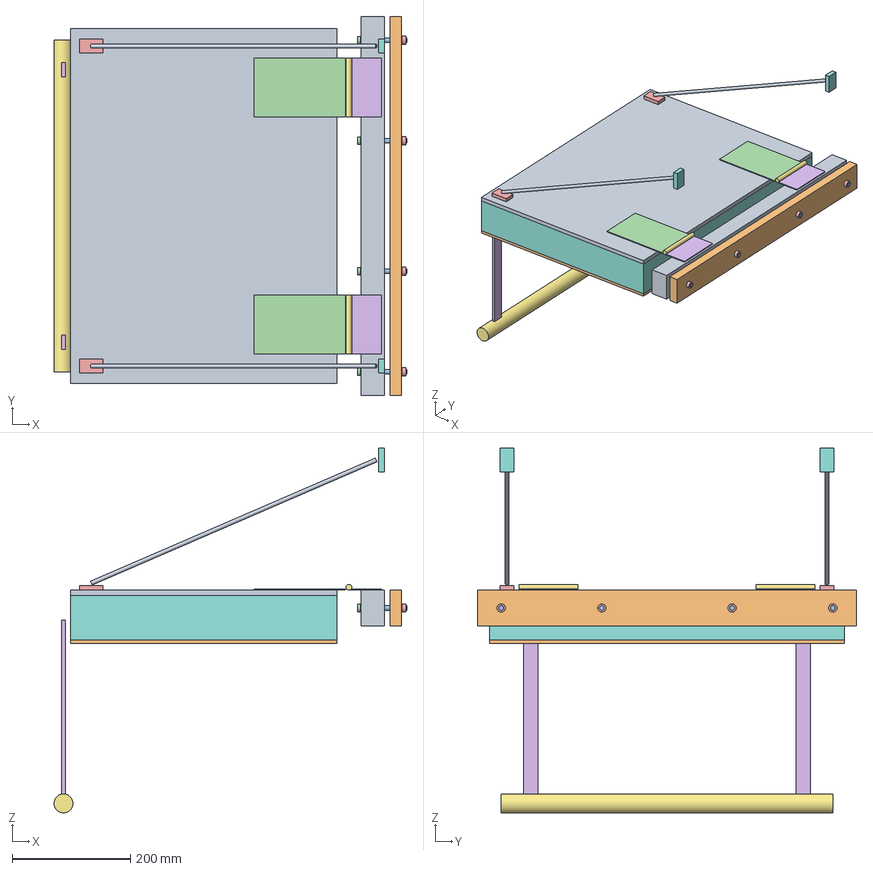
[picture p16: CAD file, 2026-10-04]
cad/step/laneskiff-stern-step.step
596.0 x 640.0 x 616.0 mm

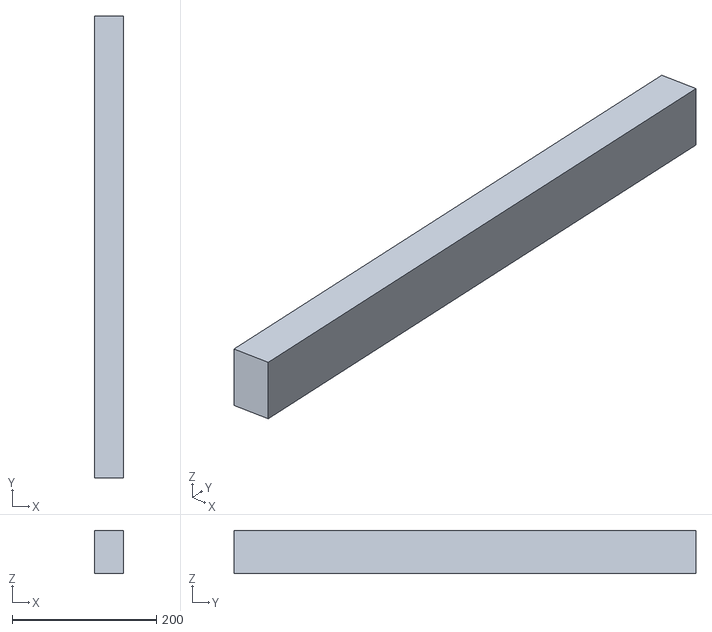
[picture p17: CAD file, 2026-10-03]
cad/stl/hinge-rail.stl
40.0 x 640.0 x 60.0

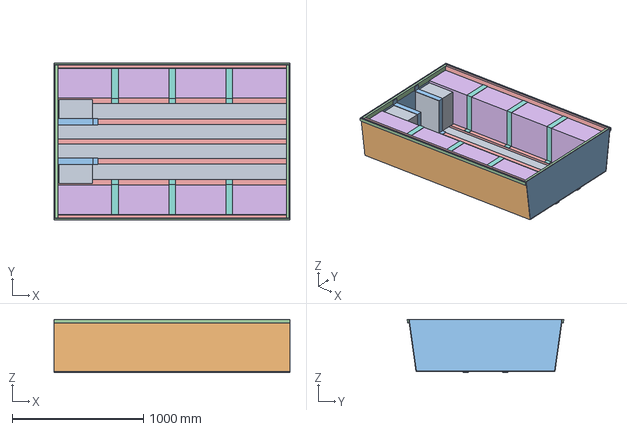
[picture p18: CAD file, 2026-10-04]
cad/step/laneskiff-aft-half.step
1800.0 x 1196.7 x 408.0 mm

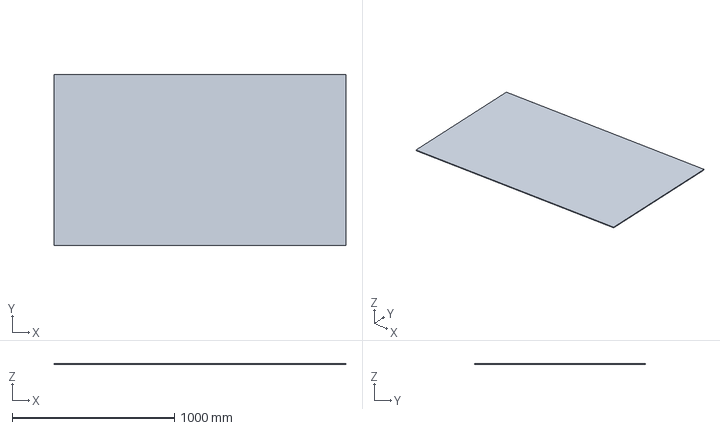
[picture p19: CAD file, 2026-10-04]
cad/step/panel-bottom-aft.step
1800.0 x 1053.6 x 6.00 mm

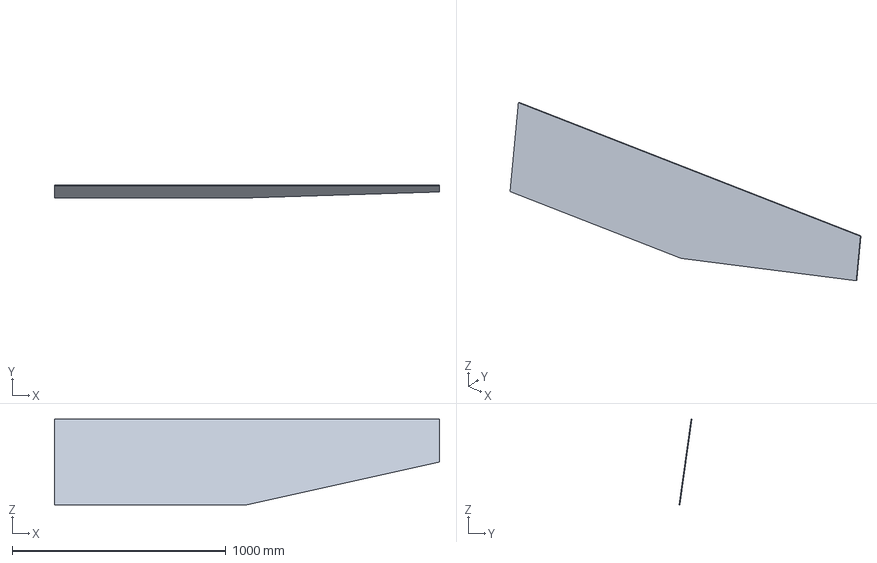
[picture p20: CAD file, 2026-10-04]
cad/step/panel-side-forward-port.step
1800.0 x 60.3 x 400.0 mm

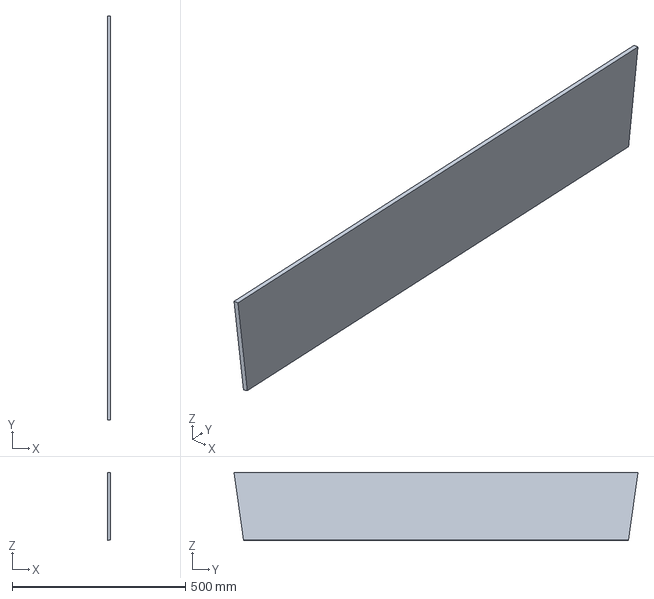
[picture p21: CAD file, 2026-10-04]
cad/step/panel-bow-transom.step
9.00 x 1164.4 x 196.0 mm

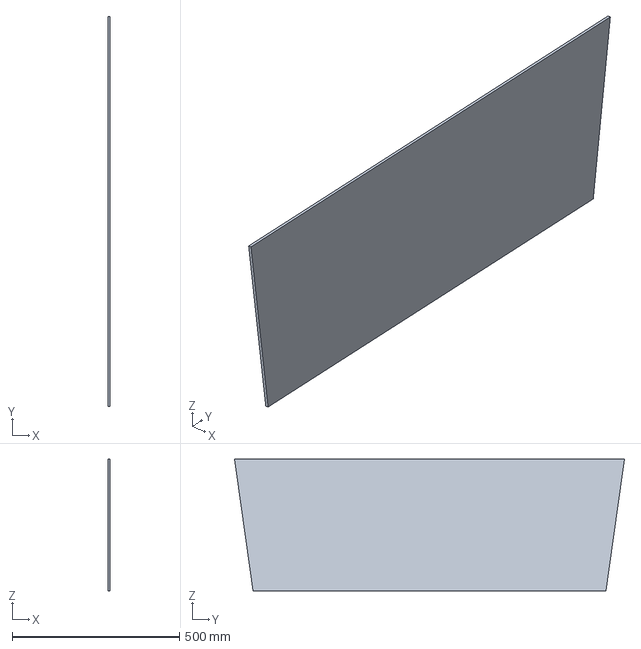
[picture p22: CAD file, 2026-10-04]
cad/step/panel-joint-bulkhead-aft.step
6.00 x 1164.4 x 394.0 mm

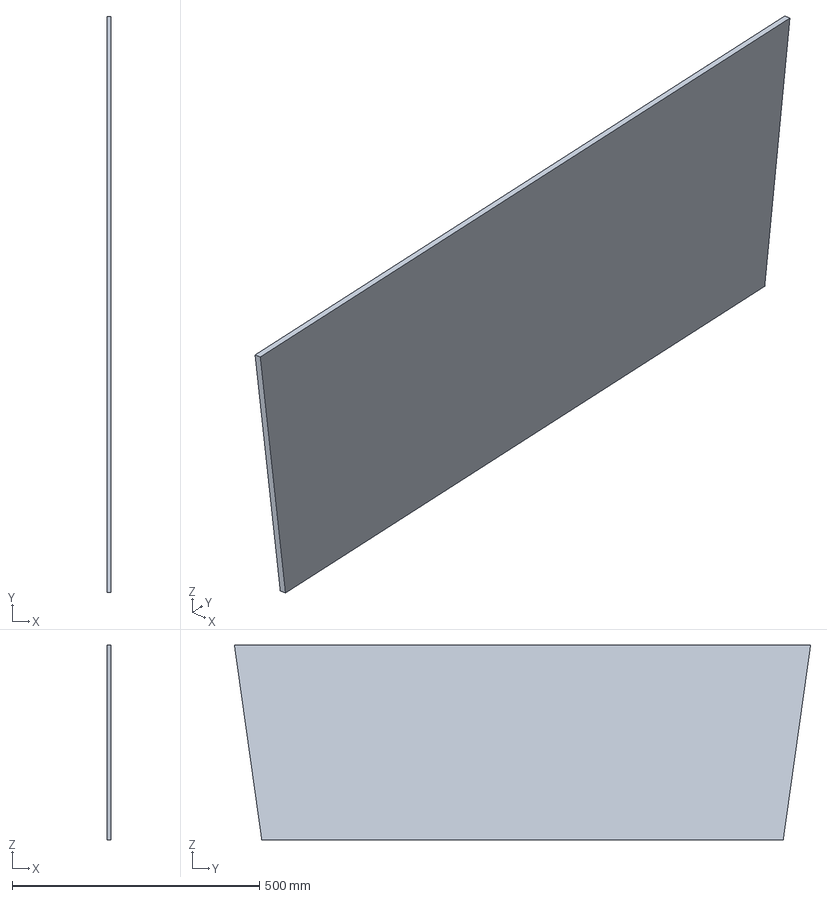
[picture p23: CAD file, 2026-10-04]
cad/step/panel-stern-transom.step
9.00 x 1164.4 x 394.0 mm

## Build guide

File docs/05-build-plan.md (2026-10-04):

---
doc_id: LSK-BLD-001
title: LaneSkiff prototype build plan
project: LaneSkiff
doc_type: Build plan
version: "0.2"
status: Draft
date: '2026-10-03'
author: Amish Chadha
license: CERN-OHL-S-2.0
revisions:
- version: "0.1"
  date: '2026-10-03'
  author: Amish Chadha
  change: First build plan; design made constructable (LSK-DDR-002)
- version: "0.2"
  date: '2026-10-03'
  author: Amish Chadha
  change: Amish's decisions of 2026-10-03 (LSK-DDR-003); okoume plywood with 4 mm sides, softwood framing, no glass inside the floor, bottom 60 mm wider, stern quarter foam modules, five-person rating and the aft-crew rule
---

# LaneSkiff prototype build plan

**Plan, not yet built.** How to build the first proof-of-concept LaneSkiff, component by component, on the plywood and epoxy path, in the light timber specification Amish chose on 2026-10-03 (LSK-DDR-003). Building and testing to it is TRL 4 work. Decisions still to be made are kept in the design decisions register (`docs/06-design-decisions.md`), not here.

> **Safety:** This plan builds a boat that will carry people in floodwater, rated for five persons. Epoxy and glass work needs gloves, eye protection and a dust mask for sanding, in a ventilated space. Nobody is carried, and no boarding or swamp trial is run, until the safety stops in section 6 are passed. LaneSkiff is an open engineering reference, not certified rescue equipment, and is never used in moving water.

## 1. What you are building

Every component, pulled apart and numbered in build order

*Figure 1. Every component in build order, pulled apart. Both halves are shown in place along the boat.*

A flat-bottomed skiff 3.6 m long and 1.197 m wide over its rub strakes, in two closed halves of 1.8 m that bolt together. Each half is stitched and glued from flat okoume plywood panels (6 mm bottom, 4 mm sides), framed with softwood, glassed outside only, and fitted with covered foam modules along both sides. The aft half carries a floating boarding step behind its transom and two foam modules in its stern quarters; the forward half has a foam-filled bow box under a short deck. The boat is rated for five persons. Fifteen components are made (the plywood panels, softwood frames, inwales and stringers, the bench modules, the stern quarter modules, the bow box, the step rail, float and kick rung, and the push pole); the rest are bought (foam sheet, HDPE strip, bolts and nut plates, hinges, webbing, handles, paddles, rope). The parts cost about USD 1,960 from the bill of materials. The hull weighs about 88 kg; each half (about 50 and 38 kg) is carried by two people with the shoulder slings.

## 2. What changed to make it buildable

*Table 1. Changes from the concept.*

| Component | The concept had | The buildable design has | Why |
| --- | --- | --- | --- |
| Hull | A hull shape | Three flat bottom panels and four flat side panels, stitched and glued with epoxy fillets and glass tape | Every panel is cut flat from a standard sheet |
| The split | One mid bulkhead | Two bulkheads, one closing each half, each with a hardwood ring frame | Each half floats alone; the joint needs no seal |
| The joint | Bolts | Eight stainless M10 bolts from the forward side into nut plates on the aft frame, and two alignment pins | One spanner joins the halves |
| Side buoyancy | Blocks under benches | Foam modules in sewn tarpaulin covers, held under the inwale and strapped to a softwood rail on the floor | Lighter than plywood boxes; the straps hold the module down when swamped |
| Stern buoyancy | Nothing aft | Two 15 L foam modules in covers in the stern quarters, either side of the step opening, strapped to the transom frame | Keeps the transom well clear of the water when swamped (Amish's decision of 2026-10-03) |
| Bow buoyancy | Buoyancy in the bow | A bow box with a plywood wall and deck, filled with foam | Foam forward and high; a dry deck for the bow line |
| Floor | A floor | Three softwood stringers per half and a knuckle floor | Short floor spans; the skids screw into the stringers |
| Stern step | A hinged buoyant step | A float on strap hinges behind a hardwood rail, a 40 mm gap, stop straps and a kick rung | Nothing can be trapped as it swings; the straps take a kneeling person |
| Strakes, skids, handles | Named only | HDPE strip screwed into the timber framing; bought handles bolted through the inwales and transom frame; shoulder slings | Every fixing lands in solid timber, never in thin plywood alone |
| Push pole | A pole | Two 1.5 m sections with a joining sleeve | Stows inside one half |

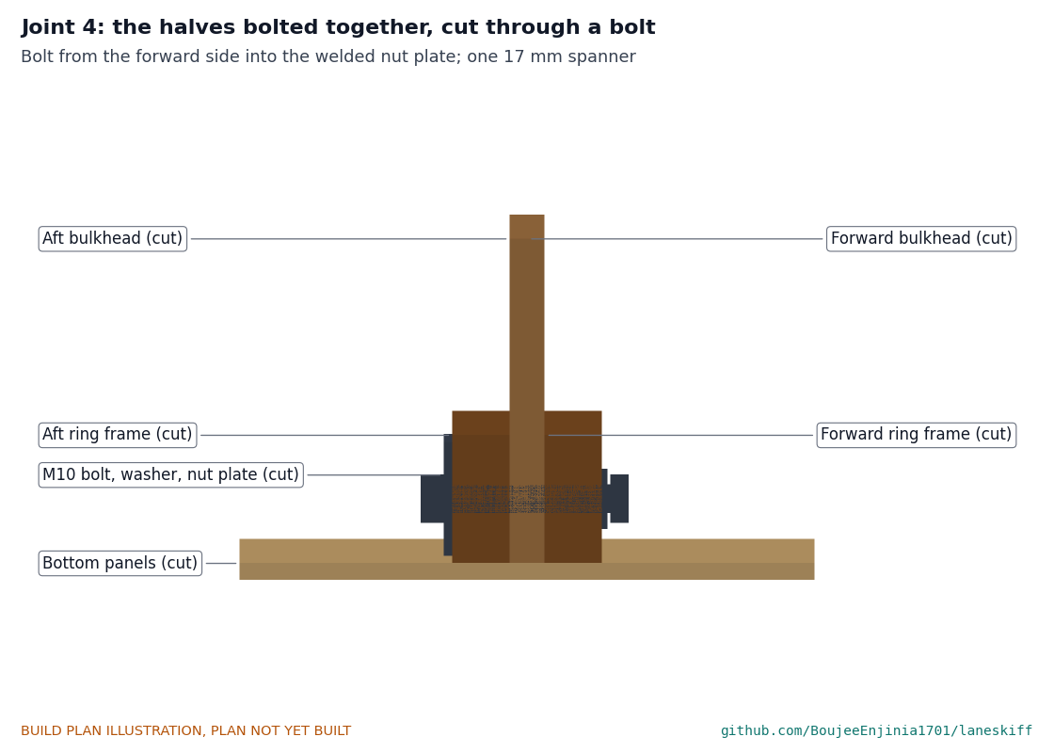
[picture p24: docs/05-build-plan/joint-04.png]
The two halves bolted together


*Figure 2. The biggest change: two closed halves, bolted through their ring frames.*

## 3. Making the components

Make every plywood panel first, seal it with epoxy on both faces, and dry-fit before any glue. The aft half and the forward half are built the same way; differences are noted.

### 3.1 Bottom panels

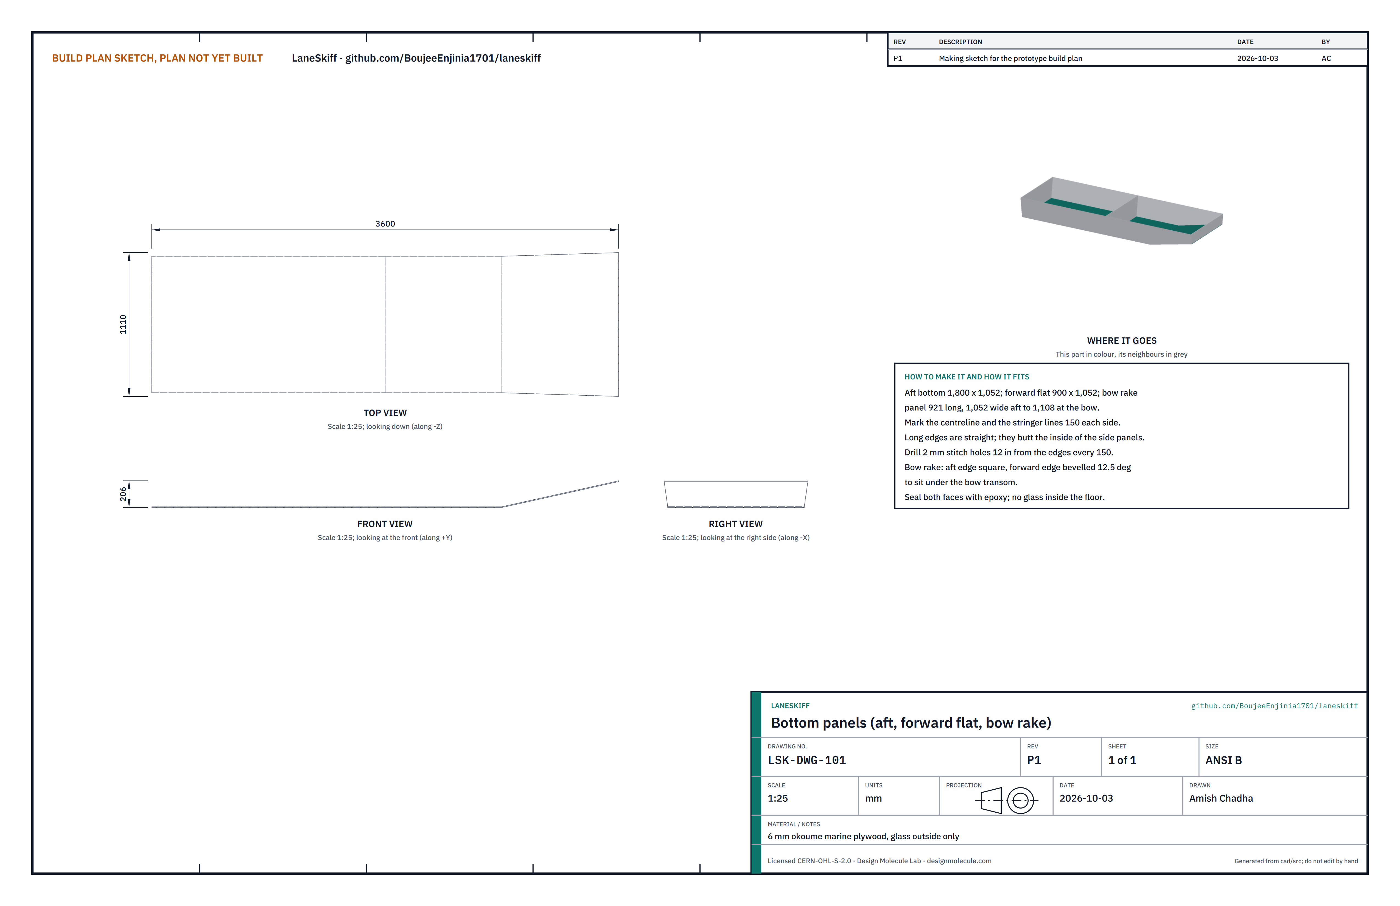
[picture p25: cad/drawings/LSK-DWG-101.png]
Making sketch: bottom panels


**What it is and what it is made from.** Three panels of 6 mm okoume marine plywood: the aft bottom (1,800 x 1,052 mm), the forward flat bottom (900 x 1,052 mm), and the bow rake panel (921 mm long, 1,052 mm wide at its aft edge widening to 1,108 mm at the bow, because the sides flare). The aft bottom takes one sheet; the forward flat bottom and bow rake panel share the second.

**How to make it.**

1. Mark the centreline and the lines of the three stringers (on the centreline and 150 mm each side) on the inside face.
2. Cut the straight long edges; they butt against the inside of the side panels.
3. Bevel the forward edge of the bow rake panel 12.5 degrees so it sits flat under the bow transom.
4. Drill 2 mm stitching holes 12 mm in from the long edges every 150 mm.
5. Seal both faces with epoxy. The inside of the floor gets two coats of epoxy and no glass.

**How it fits the parts next to it.** The side panels stand on the outside of the bottom panel's long edges and their bottom edges are flush with its underside. Inside, an epoxy fillet fills the corner; outside, 100 mm glass tape runs along the chine.

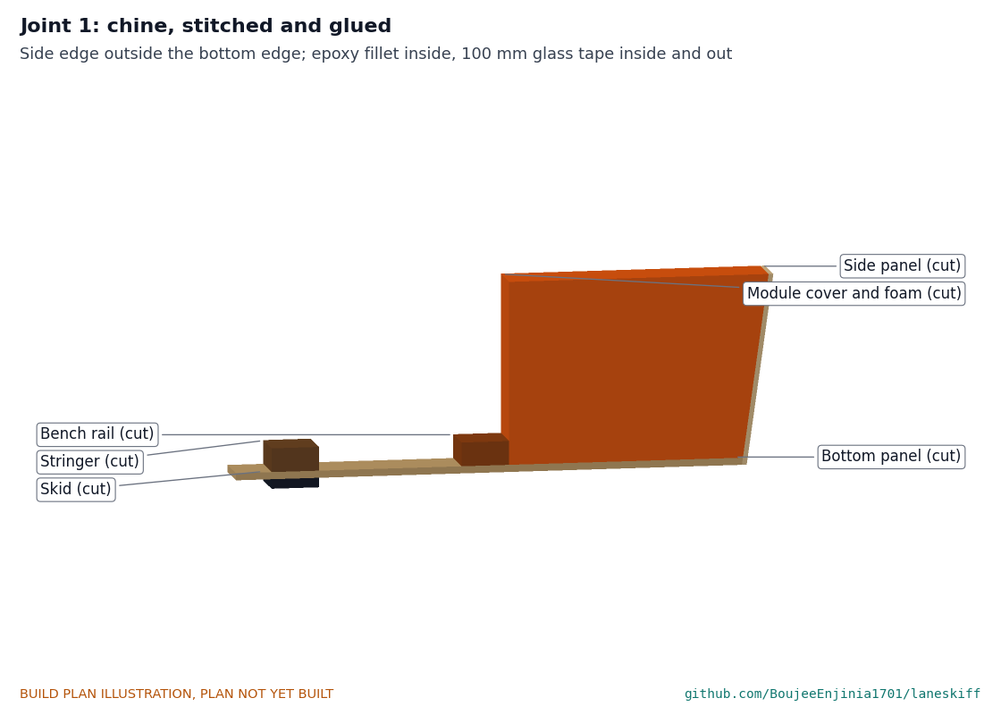
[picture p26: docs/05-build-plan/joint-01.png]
Chine joint, cut across


*Figure 3. The chine: side panel outside the bottom edge, stringer and bench rail on the floor, skid below.*

**Check before moving on.** Each panel within 2 mm of size; diagonals of the aft bottom equal within 3 mm.

### 3.2 Side panels

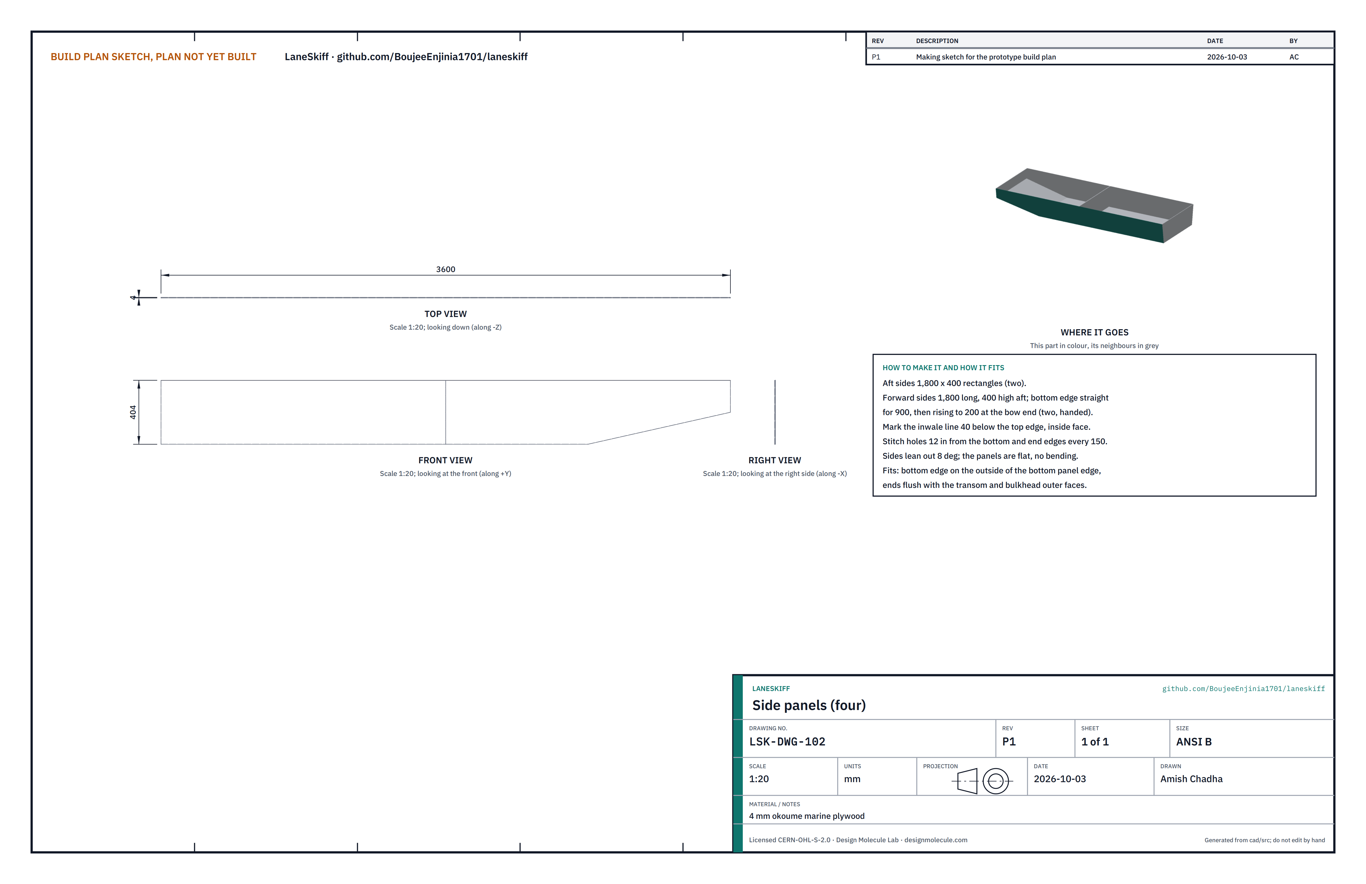
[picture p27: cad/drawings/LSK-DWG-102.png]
Making sketch: side panels


**What it is and what it is made from.** Four panels of 4 mm okoume marine plywood, 1,800 mm long. The thinner sides save weight; handle them flat and support them well while stitching. The two aft sides are 400 mm high rectangles. The two forward sides are 400 mm high at their aft end, with the bottom edge straight for 900 mm and then rising to 200 mm at the bow end; make them as a mirrored pair.

**How to make it.**

1. Cut both aft sides from one sheet and both forward sides from another, two to a sheet.
2. Mark the inwale line 40 mm below the top edge on the inside face.
3. Drill stitching holes 12 mm in from the bottom and end edges every 150 mm.
4. Seal both faces.

**How it fits the parts next to it.** The panels lean out 8 degrees from vertical. Their ends are flush with the outer faces of the transom, bulkhead and bow transom. They stay flat; there is no bending.

**Check before moving on.** Forward sides are a true mirrored pair: lay one on the other, edges within 2 mm.

### 3.3 Stern transom

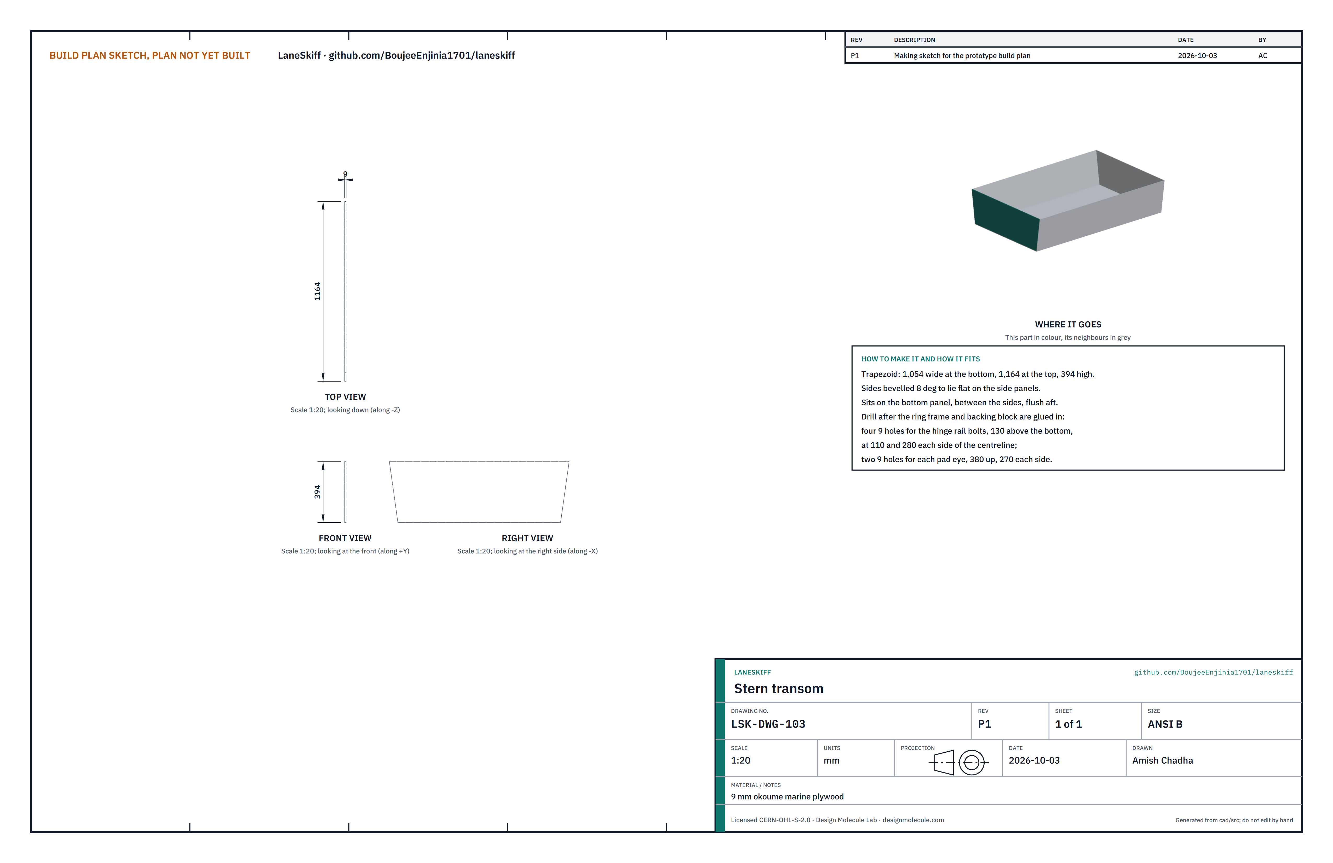
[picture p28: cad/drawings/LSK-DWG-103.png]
Making sketch: stern transom


**What it is and what it is made from.** 9 mm okoume marine plywood, a trapezoid 394 mm high, about 1,054 mm wide at the bottom and 1,164 mm at the top, with both side edges bevelled 8 degrees.

**How to make it.**

1. Cut the trapezoid and bevel the side edges.
2. Seal both faces.
3. After the ring frame and backing block are glued in (section 3.6 and 3.11), drill the four 9 mm holes for the hinge rail bolts, 130 mm above the bottom, at 110 mm and 280 mm each side of the centreline, and the holes for the two stop strap pad eyes, 380 mm up and 270 mm each side.

**How it fits the parts next to it.** It sits on the aft bottom panel, between the side panels, flush with their aft ends. Fillets and tape inside; tape outside.

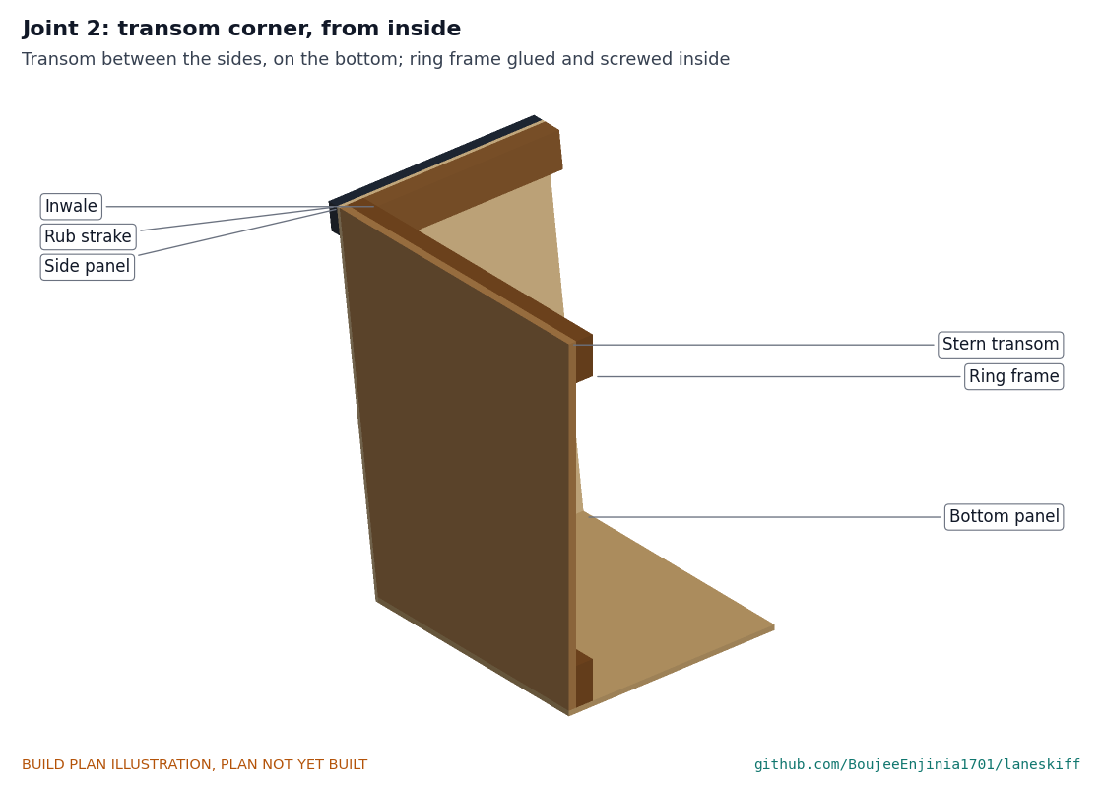
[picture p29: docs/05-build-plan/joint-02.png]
Transom corner from inside


*Figure 4. Transom corner: transom between the sides, ring frame inside, inwale and rub strake at the top.*

**Check before moving on.** Square to the bottom within 1 degree.

### 3.4 Bow transom

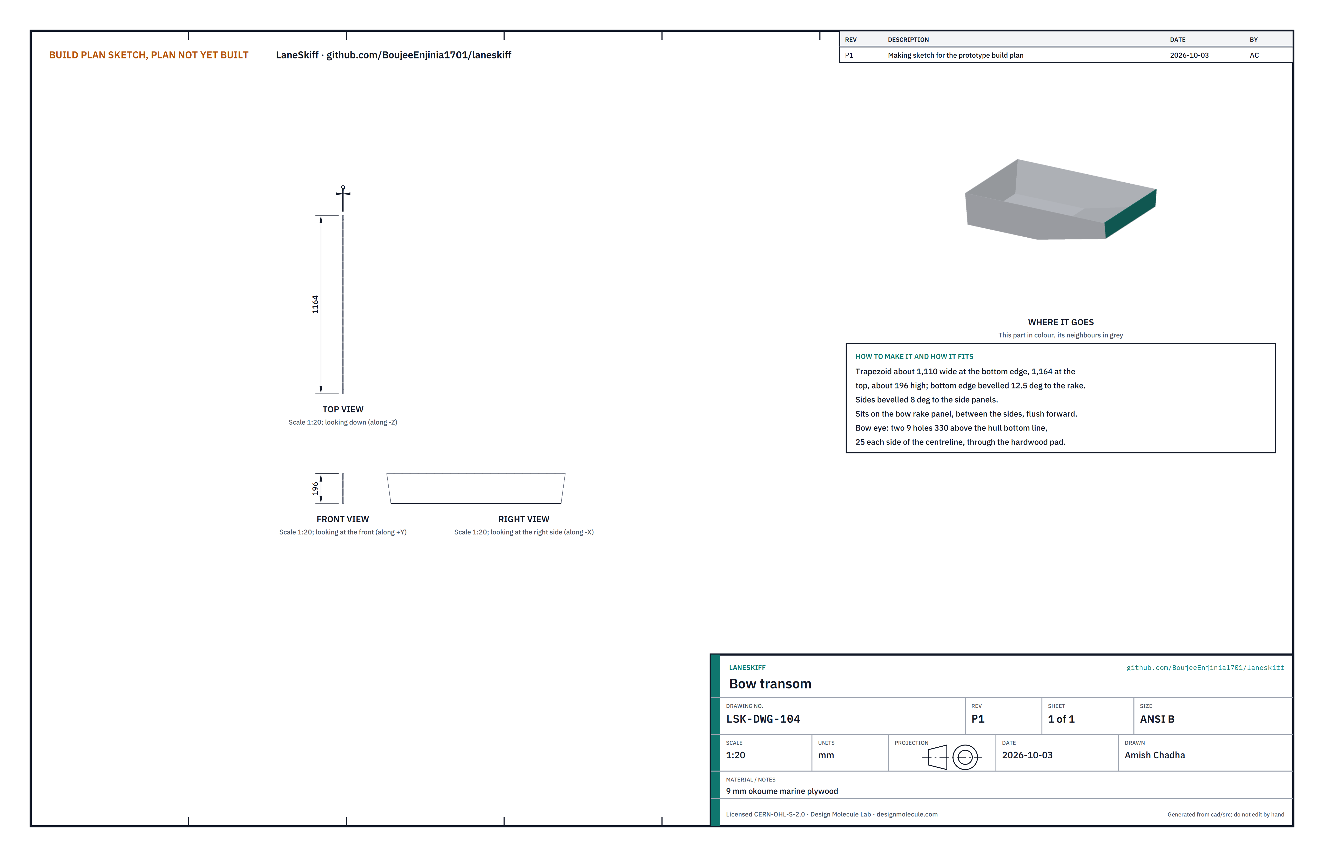
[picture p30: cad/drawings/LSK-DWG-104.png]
Making sketch: bow transom


**What it is and what it is made from.** 9 mm okoume marine plywood, about 1,109 mm wide at the bottom and 1,164 mm at the top, about 196 mm high, with its bottom edge bevelled 12.5 degrees to the rake and its sides bevelled 8 degrees.

**How to make it.** Cut and bevel; drill two 9 mm holes for the bow eye, 330 mm above the line of the hull bottom and 25 mm each side of the centreline; seal.

**How it fits the parts next to it.** It sits on the bow rake panel between the forward side panels, flush with their bow ends. The bow eye pad is glued to its inside (section 3.10).

**Check before moving on.** Top edge level with the side panels' top edges.

### 3.5 Joint bulkheads

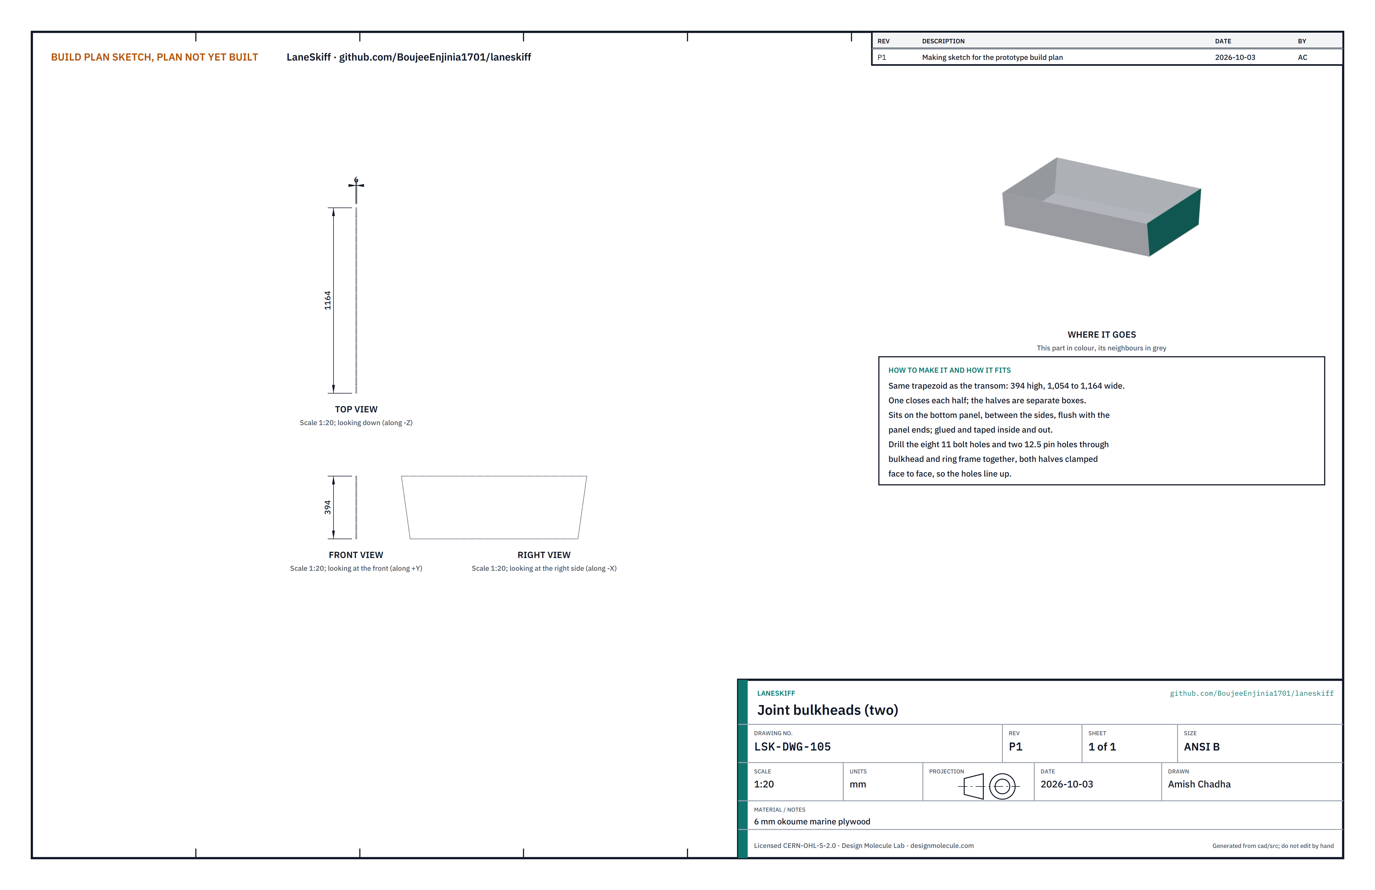
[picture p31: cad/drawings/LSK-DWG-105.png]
Making sketch: joint bulkheads


**What it is and what it is made from.** Two panels of 6 mm okoume marine plywood, the same trapezoid as the stern transom.

**How to make it.** Cut both from one pattern; seal. Drill the bolt and pin holes later, through bulkhead and ring frame together, with both halves clamped face to face (section 3.6).

**How it fits the parts next to it.** Each closes its half at the joint: it sits on the bottom panel between the side panels, flush with their ends, filleted and taped inside and out. The two bulkheads touch face to face when the boat is assembled.

Halves joint, cut through a bolt

*Figure 5. Aft ring frame, aft bulkhead, forward bulkhead, forward ring frame, clamped by an M10 bolt into a nut plate.*

**Check before moving on.** With the two halves standing together, the bulkhead faces touch all round (no gap over 1 mm).

### 3.6 Ring frames

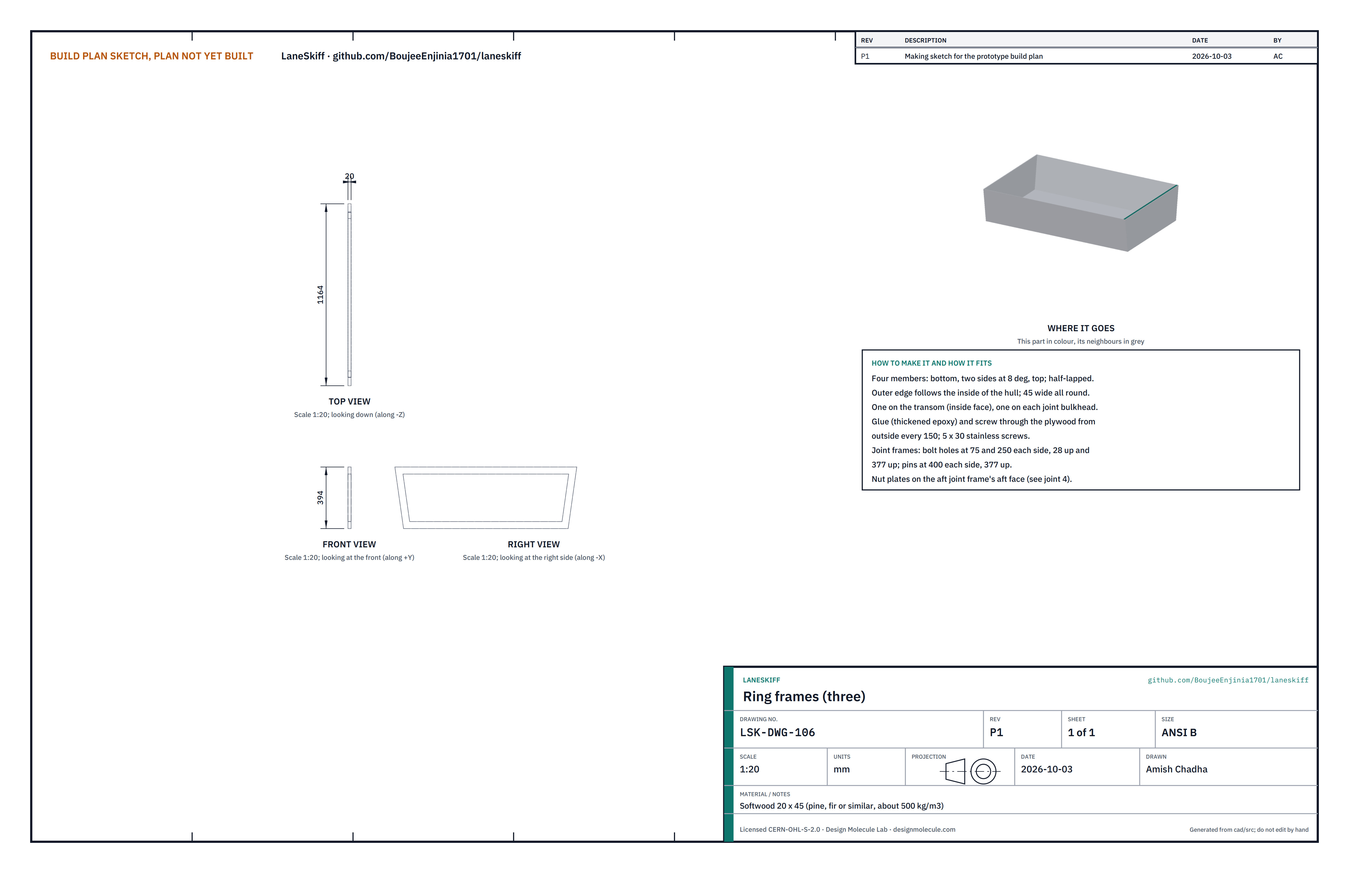
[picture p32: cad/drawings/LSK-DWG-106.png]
Making sketch: ring frames


**What it is and what it is made from.** Three rings of softwood 20 x 45 mm (pine, fir or similar, kiln dried and free of knots): one inside the stern transom and one on each joint bulkhead. Each ring is four members (bottom, two sides at 8 degrees, top), half-lapped at the corners, following the inside of the hull with a 45 mm wide face.

**How to make it.**

1. Cut the members, lay the ring on its bulkhead, mark and cut the half-laps.
2. Glue the ring to the plywood with thickened epoxy and screw through the plywood from outside every 150 mm with 5 x 30 stainless screws.
3. Joint frames only: with both halves clamped together, drill eight 11 mm bolt holes (at 75 mm and 250 mm each side of the centreline, 28 mm above the floor line and 377 mm up) and two 12.5 mm pin holes (400 mm each side, 377 mm up) through frame and bulkhead of both halves at once.
4. Screw a nut plate (a 40 x 40 x 3 mm steel plate with an M10 nut welded on) over each bolt hole on the aft face of the aft joint frame. Epoxy the two pins into the aft frame.

**How it fits the parts next to it.** The frames butt against the side panels, bottom and transom or bulkhead; the inwales and stringers end against their faces.

**Check before moving on.** A bolt runs freely through all four layers into every nut plate by hand.

### 3.7 Inwales

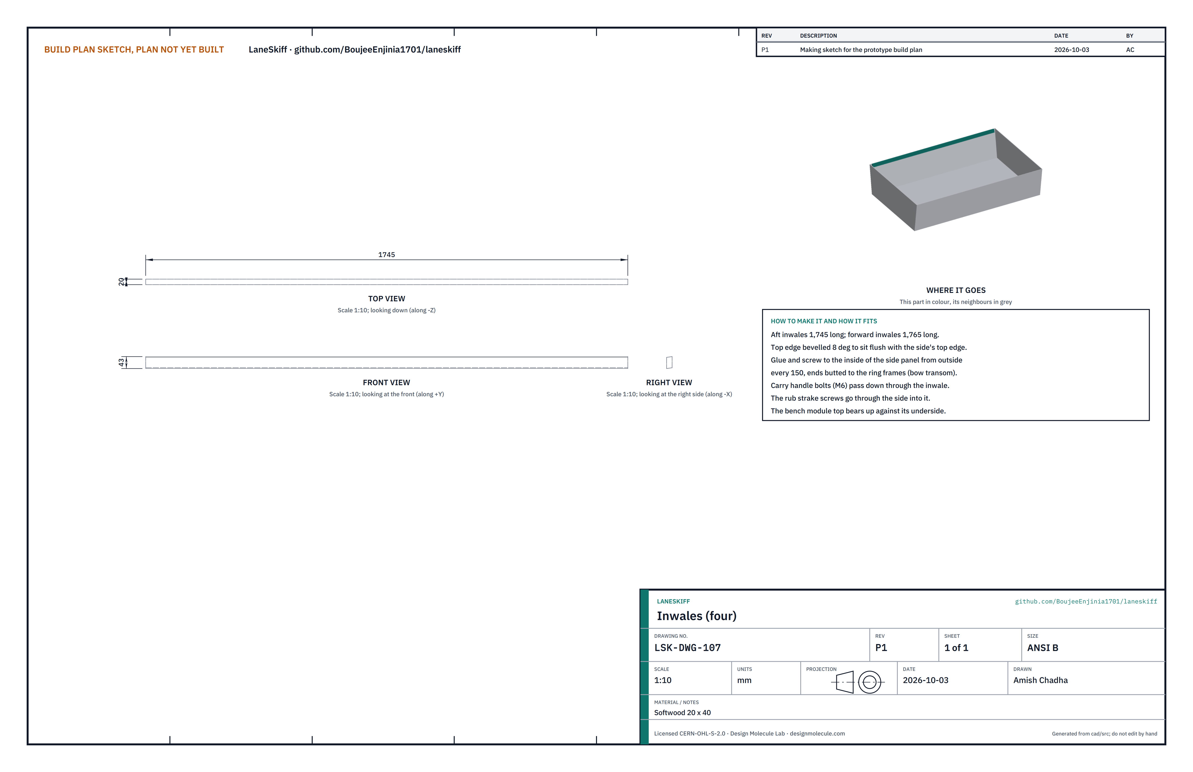
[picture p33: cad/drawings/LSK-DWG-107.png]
Making sketch: inwales


**What it is and what it is made from.** Four lengths of softwood 20 x 40 mm: aft inwales 1,745 mm, forward inwales 1,765 mm.

**How to make it.** Bevel the top edge 8 degrees; glue to the inside of the side panel along the inwale line, screwing from outside every 150 mm; ends butt the ring frames (and the bow transom forward).

**How it fits the parts next to it.** Its top is flush with the side's top edge. The carry handle bolts pass down through it, the rub strake screws go into it, and the top of each bench module bears up against its underside.

**Check before moving on.** Top edge flush with the side within 1 mm along its length.

### 3.8 Stringers and knuckle floor

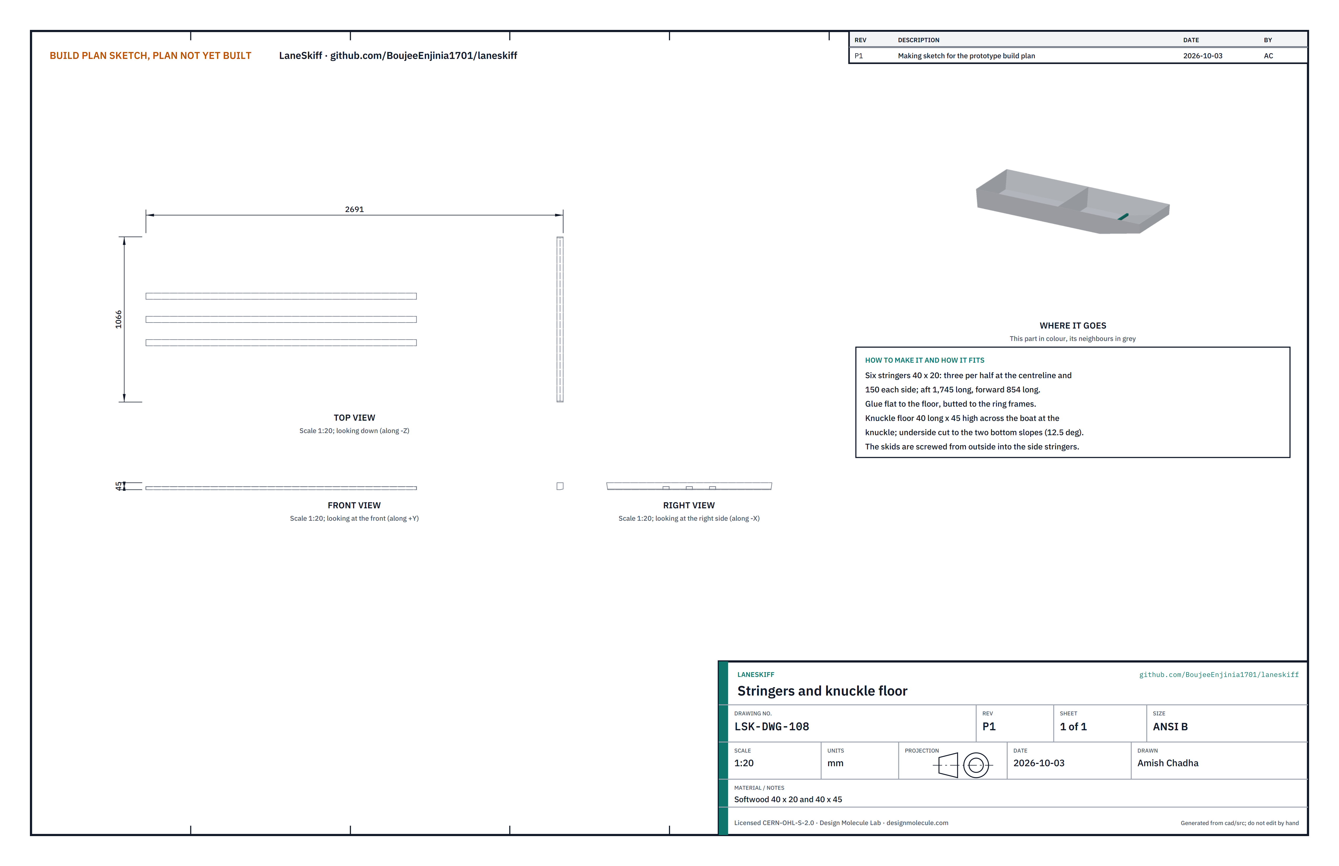
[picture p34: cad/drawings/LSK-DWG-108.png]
Making sketch: stringers and knuckle floor


**What it is and what it is made from.** Six softwood stringers 40 x 20 mm (three per half: on the centreline and 150 mm each side; 1,745 mm long aft, 854 mm forward) and a knuckle floor 40 mm long and 45 mm high across the forward half at the knuckle, its underside cut to the two bottom slopes.

**How to make it.** Glue the stringers flat to the floor on their marked lines, ends butted to the ring frames and the knuckle floor. Glue and screw the knuckle floor across both bottom panels at the knuckle.

**How it fits the parts next to it.** The bow rake panel and the forward flat bottom butt at the knuckle on top of the knuckle floor; tape outside and fillets inside close the seam.

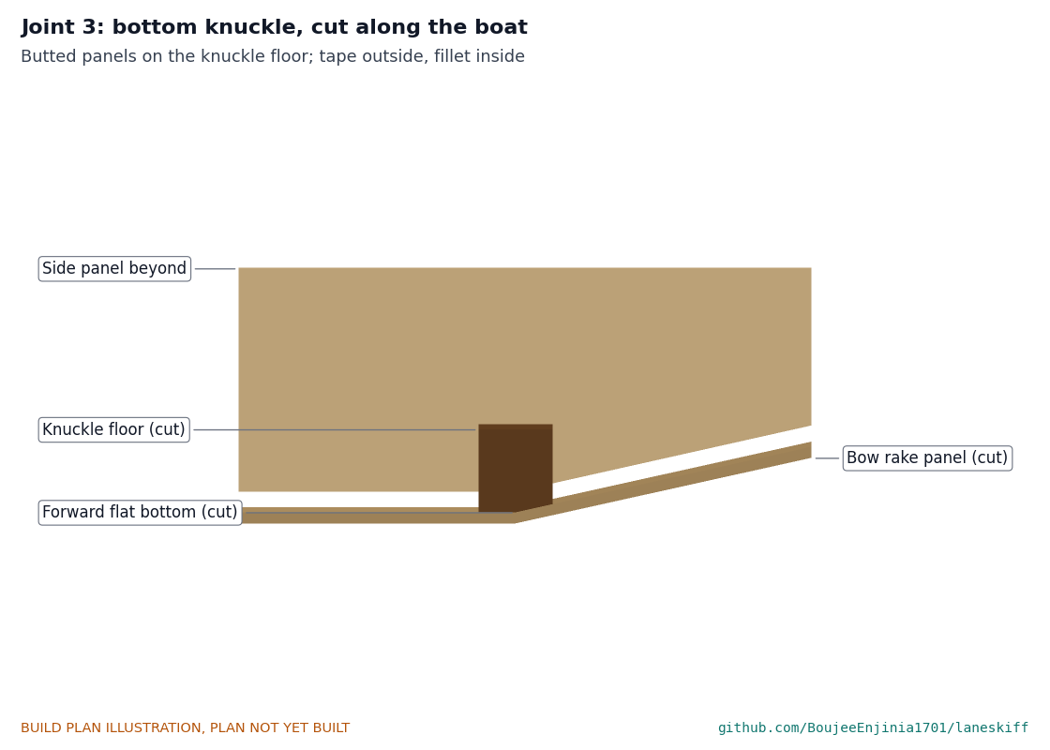
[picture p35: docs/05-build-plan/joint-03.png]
Bottom knuckle, cut along the boat


*Figure 6. The knuckle: the two bottom panels butt on the knuckle floor.*

**Check before moving on.** No stringer rocks; fillets continuous.

### 3.9 Bench modules

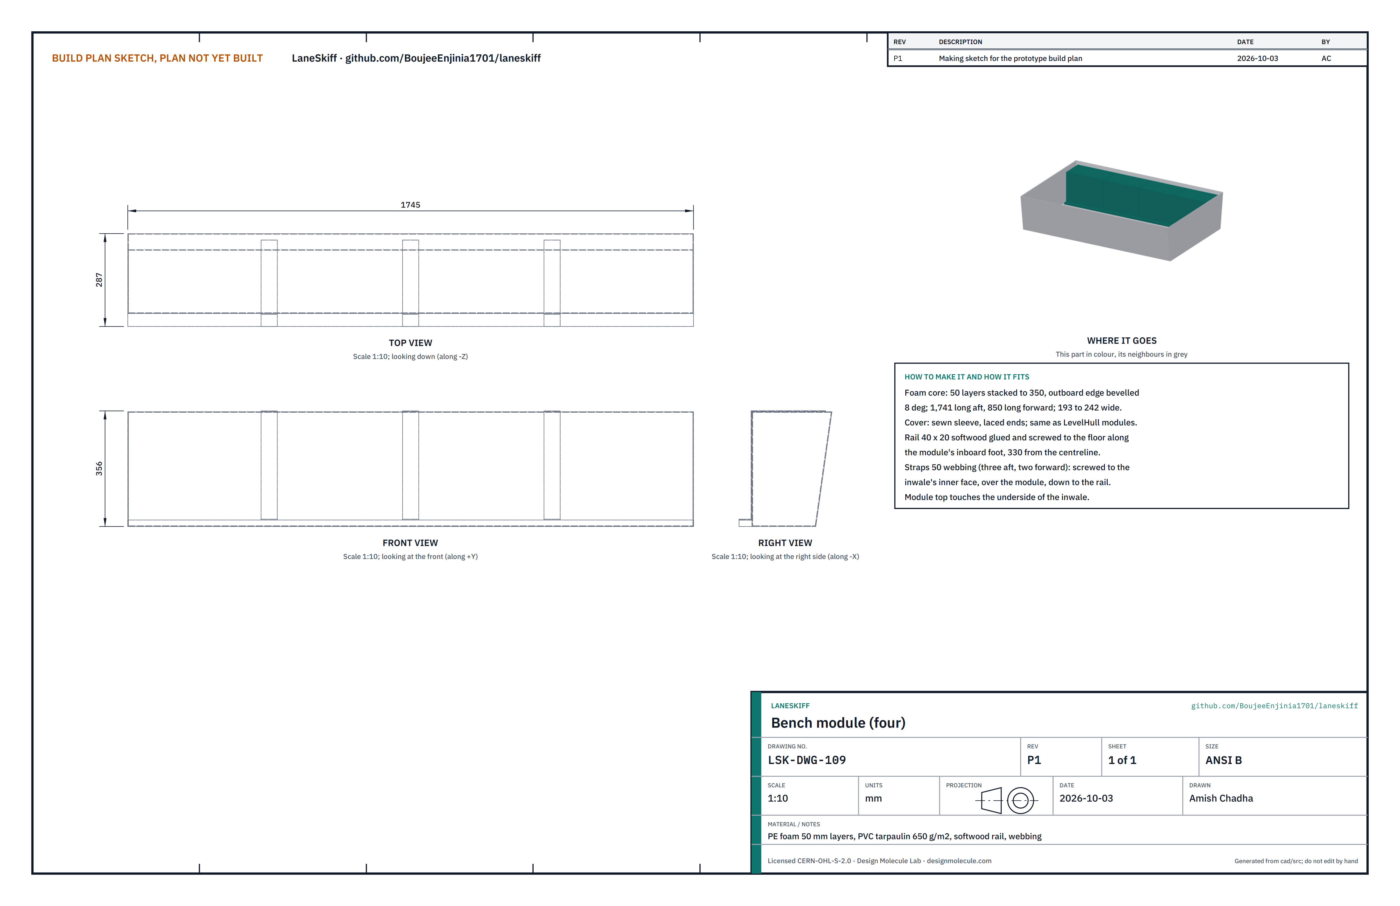
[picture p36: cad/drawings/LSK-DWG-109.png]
Making sketch: bench module


**What it is and what it is made from.** Four modules, one each side of each half: a core of closed-cell polyethylene foam in 50 mm layers, stacked 350 mm high, with its outboard edge bevelled 8 degrees to lie on the side (193 to 242 mm wide, 1,741 mm long aft, 850 mm forward); a sewn sleeve of PVC-coated polyester tarpaulin with laced ends, as for the LevelHull modules; a softwood bench rail 40 x 20 mm on the floor along the module's inboard foot, 330 mm from the centreline; and webbing straps (three per aft module, two per forward module).

**How to make it.**

1. Cut the foam layers, bevel the outboard edges, stack them; no glue.
2. Sew the sleeve to the stack size with two rows of UV-stabilised stitching; slide the stack in and lace the ends.
3. Glue and screw the bench rails to the floor.
4. Cut the straps 50 mm webbing, heat-seal the ends.

**How it fits the parts next to it.** The module sits on the floor against the side panel, between the ring frames, with its top touching the underside of the inwale. Each strap is screwed to the inwale's inner face with two stainless screws and a penny washer, runs over the module top and down its inboard face, and is screwed to the top of the bench rail.

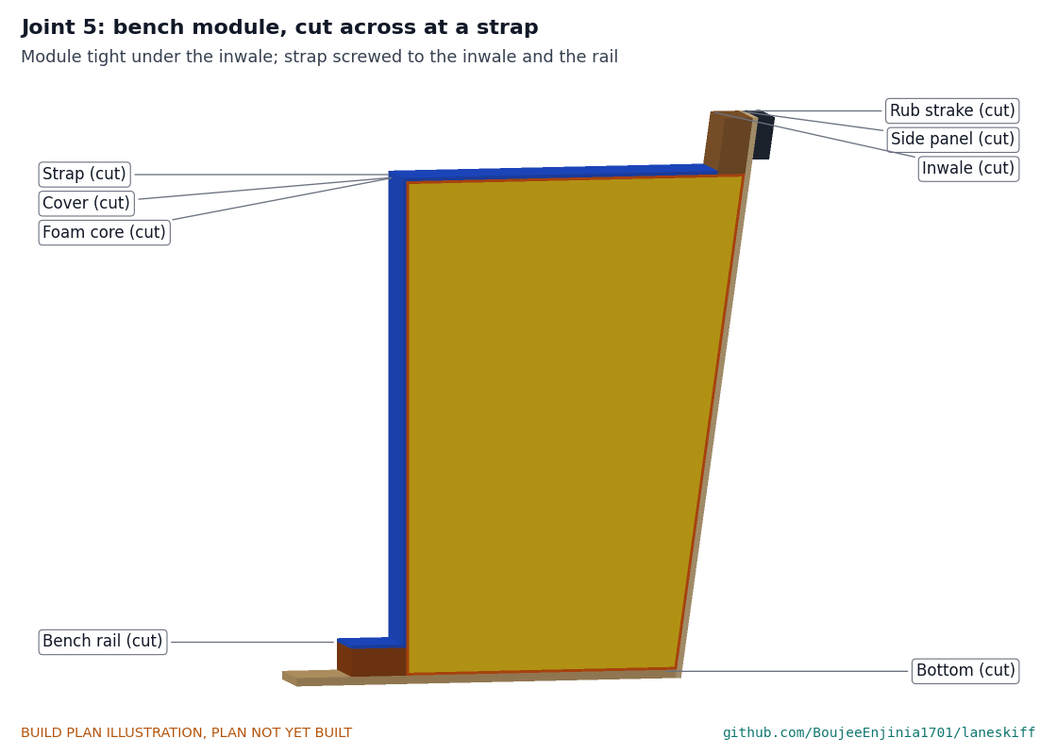
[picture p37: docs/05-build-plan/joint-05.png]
Bench module, cut across at a strap


*Figure 7. Bench module tight under the inwale, strapped to the inwale and the bench rail.*

**Check before moving on.** The module cannot be lifted by hand at any strap.

### 3.10 Bow box

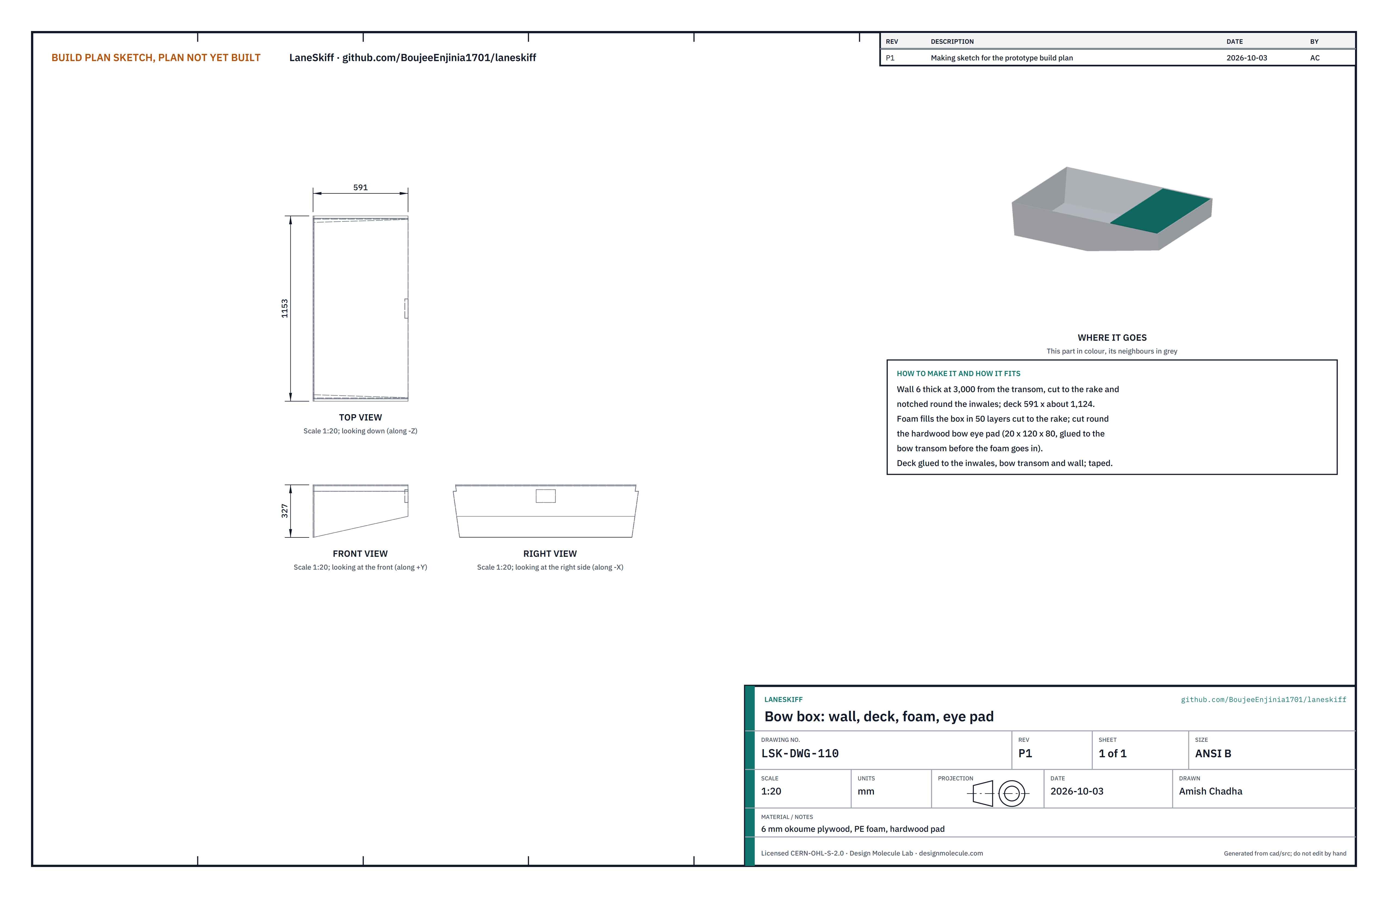
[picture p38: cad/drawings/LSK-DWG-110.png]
Making sketch: bow box


**What it is and what it is made from.** A 6 mm okoume plywood wall standing 3.0 m forward of the transom, cut to the rake and notched round the inwales; a 6 mm deck 591 mm long and about 1,124 mm wide; foam layers filling the box; and a hardwood pad 20 x 120 x 80 mm for the bow eye.

**How to make it.**

1. Glue the pad to the inside of the bow transom; fit the bow eye (a stainless U-bolt) through transom and pad with its backing plate and nuts inside.
2. Glue in the wall; fillet and tape it to the bottom and sides.
3. Cut the foam layers to the rake and round the pad and nuts; pack the box.
4. Glue the deck to the inwales, bow transom and wall; tape the seams.

**How it fits the parts next to it.** The deck lies between the inwales, flush with their tops; the foam fills the box with no voids.

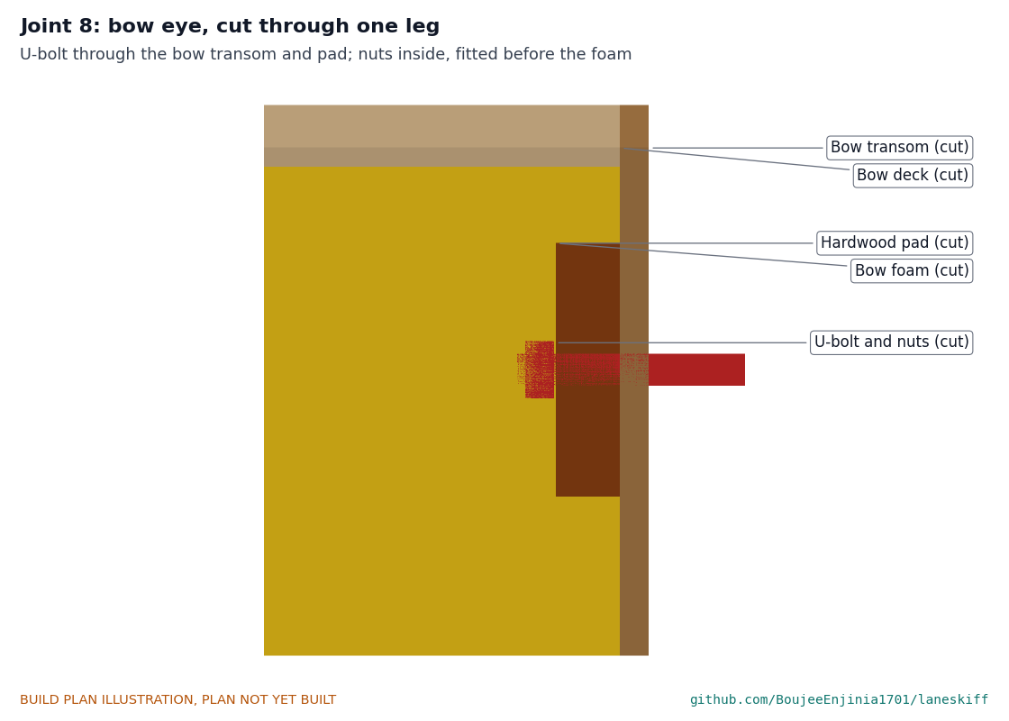
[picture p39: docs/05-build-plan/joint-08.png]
Bow eye, cut through one leg


*Figure 8. Bow eye through the bow transom and pad, nuts inside, foam round it.*

**Check before moving on.** Bow eye nuts tight before the foam goes in; the eye does not move under a hard pull by hand.

### 3.11 Hinge rail and transom backing block

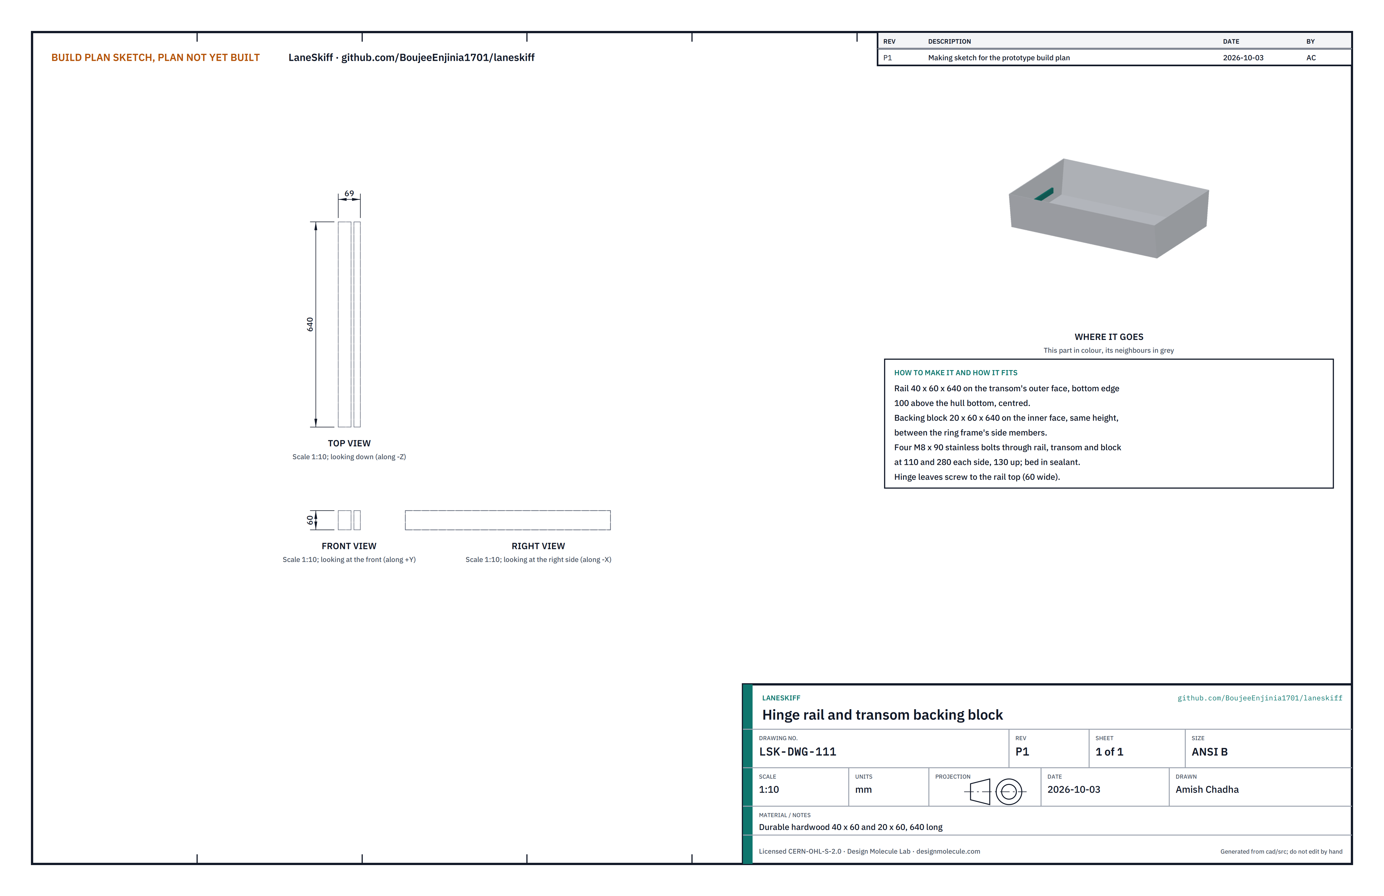
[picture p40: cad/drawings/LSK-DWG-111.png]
Making sketch: hinge rail and backing block


**What it is and what it is made from.** A hardwood rail 40 x 60 x 640 mm on the transom's outer face, its bottom edge 100 mm above the bottom of the hull, centred; and a hardwood backing block 20 x 60 x 640 mm on the inner face at the same height, between the ring frame's side members.

**How to make it.** Cut, seal, glue the backing block inside; drill through block, transom and rail together for four M8 x 90 stainless bolts at 110 mm and 280 mm each side, 130 mm up; bed the bolts in sealant.

**How it fits the parts next to it.** The strap hinges screw to the rail's top face (60 mm wide).

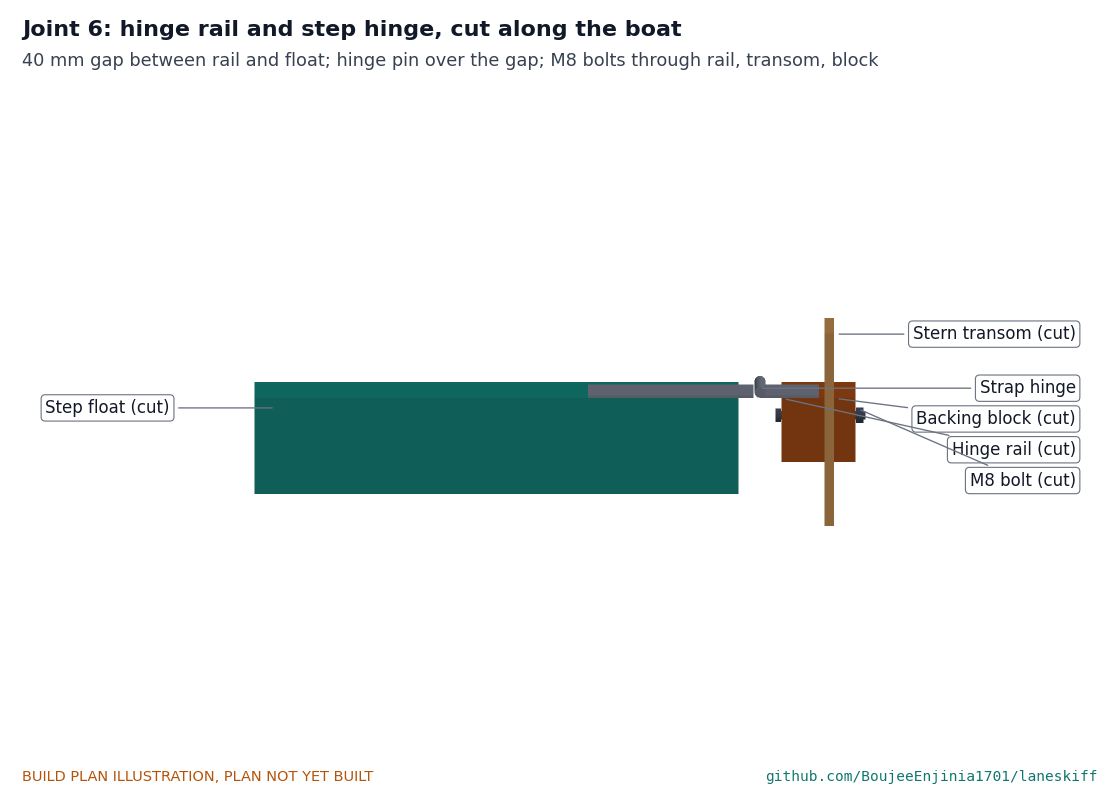
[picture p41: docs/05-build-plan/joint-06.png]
Hinge rail and step hinge, cut along the boat


*Figure 9. Hinge rail bolted through transom and backing block; the step hinge crosses the 40 mm gap to the float.*

**Check before moving on.** The rail does not move when levered with a 1 m bar.

### 3.12 Step float

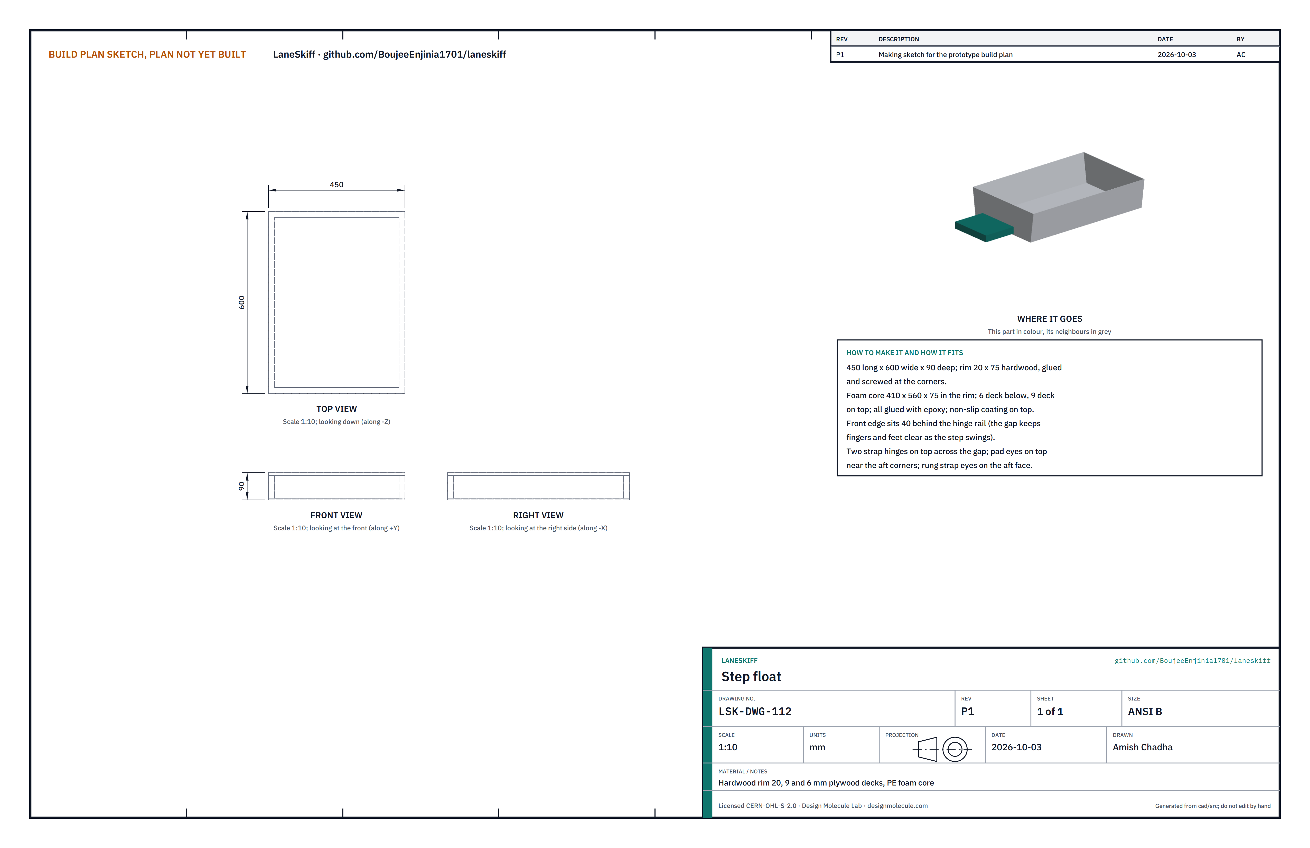
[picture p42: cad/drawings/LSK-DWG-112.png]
Making sketch: step float


**What it is and what it is made from.** A float 450 mm long, 600 mm wide and 90 mm deep: a hardwood rim 20 x 75 mm, a foam core 410 x 560 x 75 mm, a 6 mm plywood bottom deck and a 9 mm plywood top deck, all glued with epoxy; non-slip coating on top.

**How to make it.** Glue and screw the rim at the corners; glue the bottom deck on; set the foam in; glue the top deck on; coat. Fit two pad eyes on top near the aft corners and two strap eyes on the aft face.

**How it fits the parts next to it.** Its front edge sits 40 mm behind the hinge rail. Two heavy stainless strap hinges, one leaf on the rail top and one on the float top, cross the gap with their pins over it. Two webbing stop straps run from pad eyes high on the transom to the pad eyes on the float and hold it at 20 degrees below level at most.

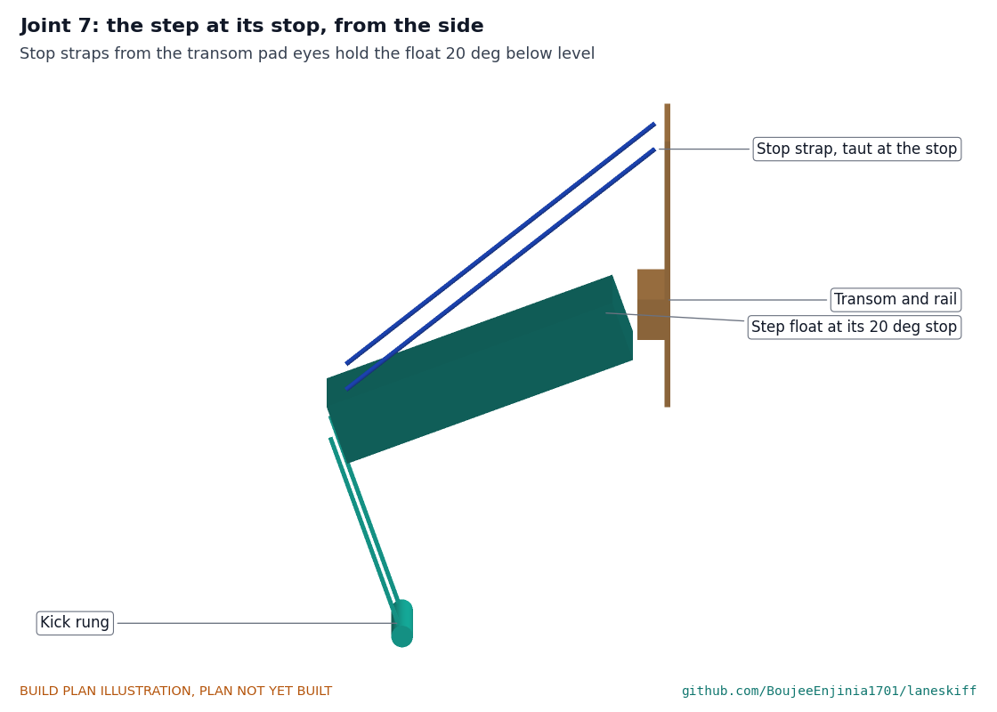
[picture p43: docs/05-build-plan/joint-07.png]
The step at its stop


*Figure 10. The step swung down to its stop, with the kick rung below.*

**Check before moving on.** The float swings from folded up to its stop without touching the rail or transom; nothing closes to less than 25 mm.

### 3.13 Kick rung

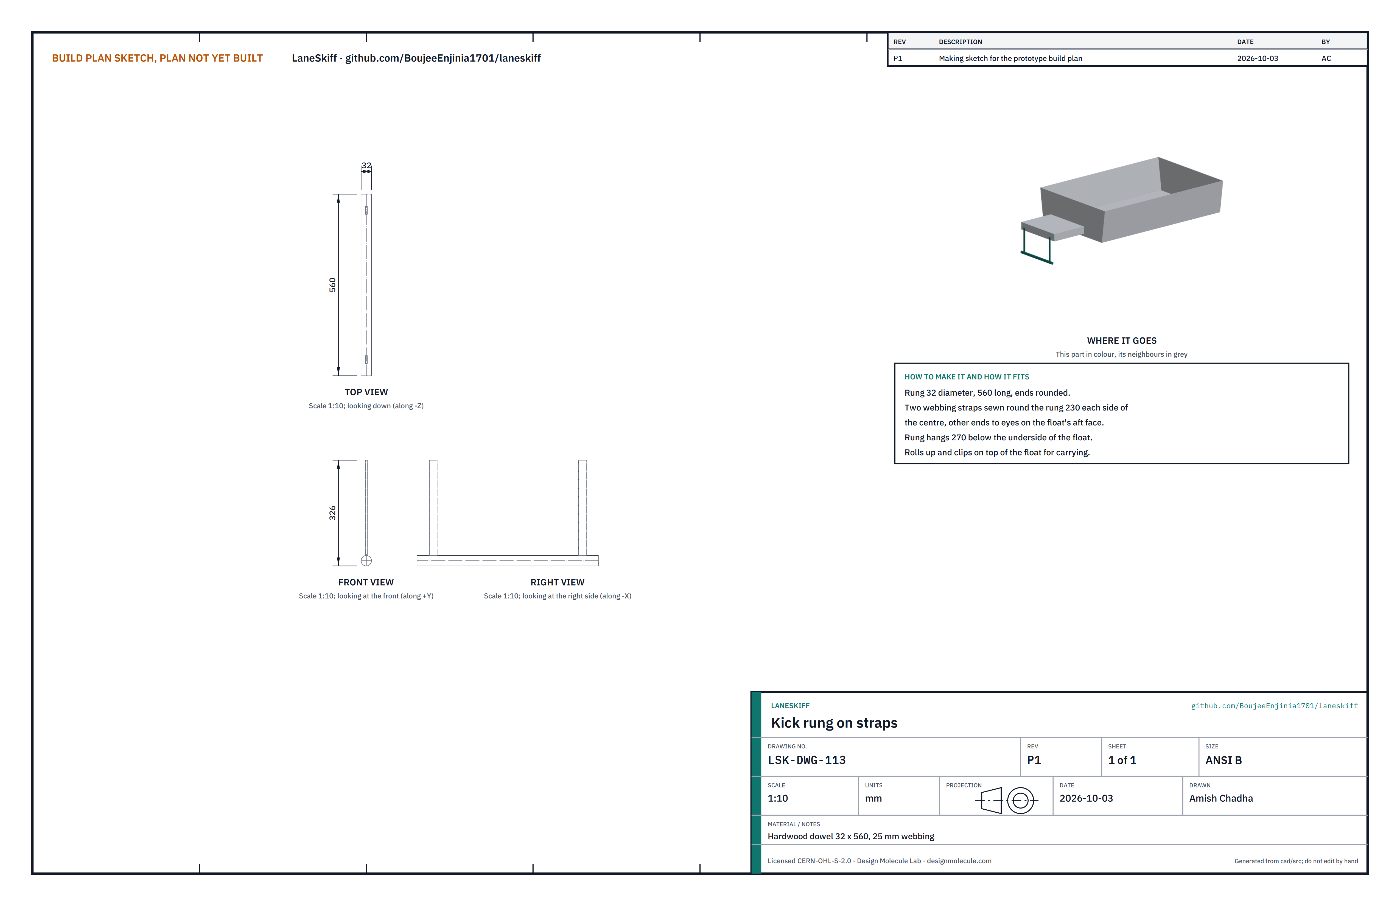
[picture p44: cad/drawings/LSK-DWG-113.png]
Making sketch: kick rung


**What it is and what it is made from.** A hardwood rung 32 mm in diameter and 560 mm long on two 25 mm webbing straps.

**How to make it.** Round the ends; sew each strap round the rung 230 mm each side of the centre; sew the other ends to the strap eyes on the float's aft face so the rung hangs 270 mm below the float's underside.

**How it fits the parts next to it.** It rolls up and clips on top of the float for carrying.

**Check before moving on.** Each strap holds a person standing on the rung (see section 6).

### 3.14 Push pole

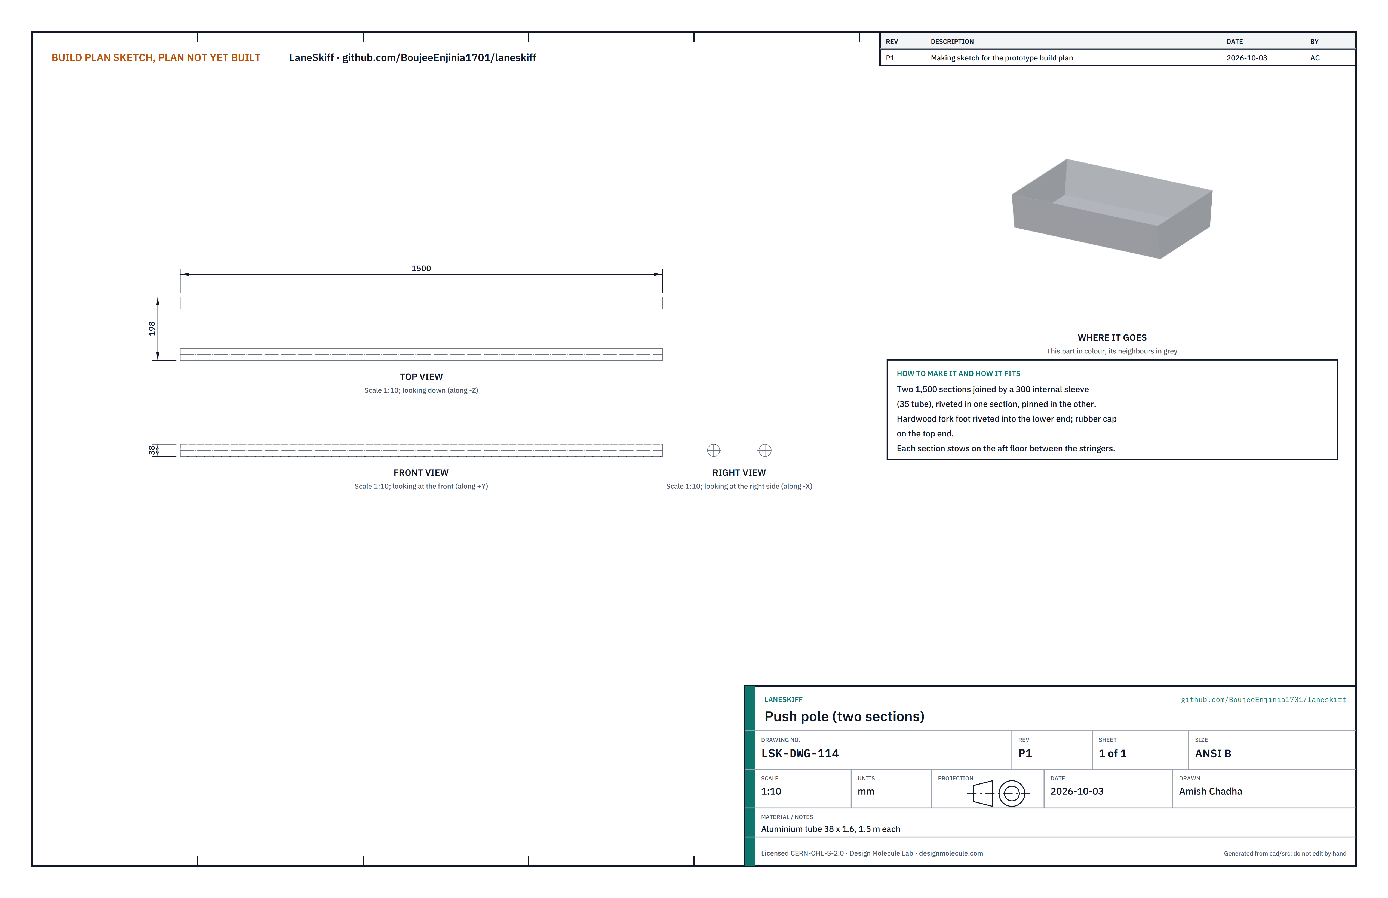
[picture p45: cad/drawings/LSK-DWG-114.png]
Making sketch: push pole


**What it is and what it is made from.** Two 1,500 mm sections of aluminium tube 38 x 1.6 mm, joined by a 300 mm internal sleeve riveted into one section and pinned into the other; a hardwood fork foot riveted into the lower end; a rubber cap on the top end.

**How to make it.** Cut, deburr, rivet the sleeve, drill the cross pin, rivet the foot.

**How it fits the parts next to it.** Each section stows on the aft floor between the stringers.

**Check before moving on.** The joined pole does not wobble at the joint.

### 3.15 Stern quarter foam modules

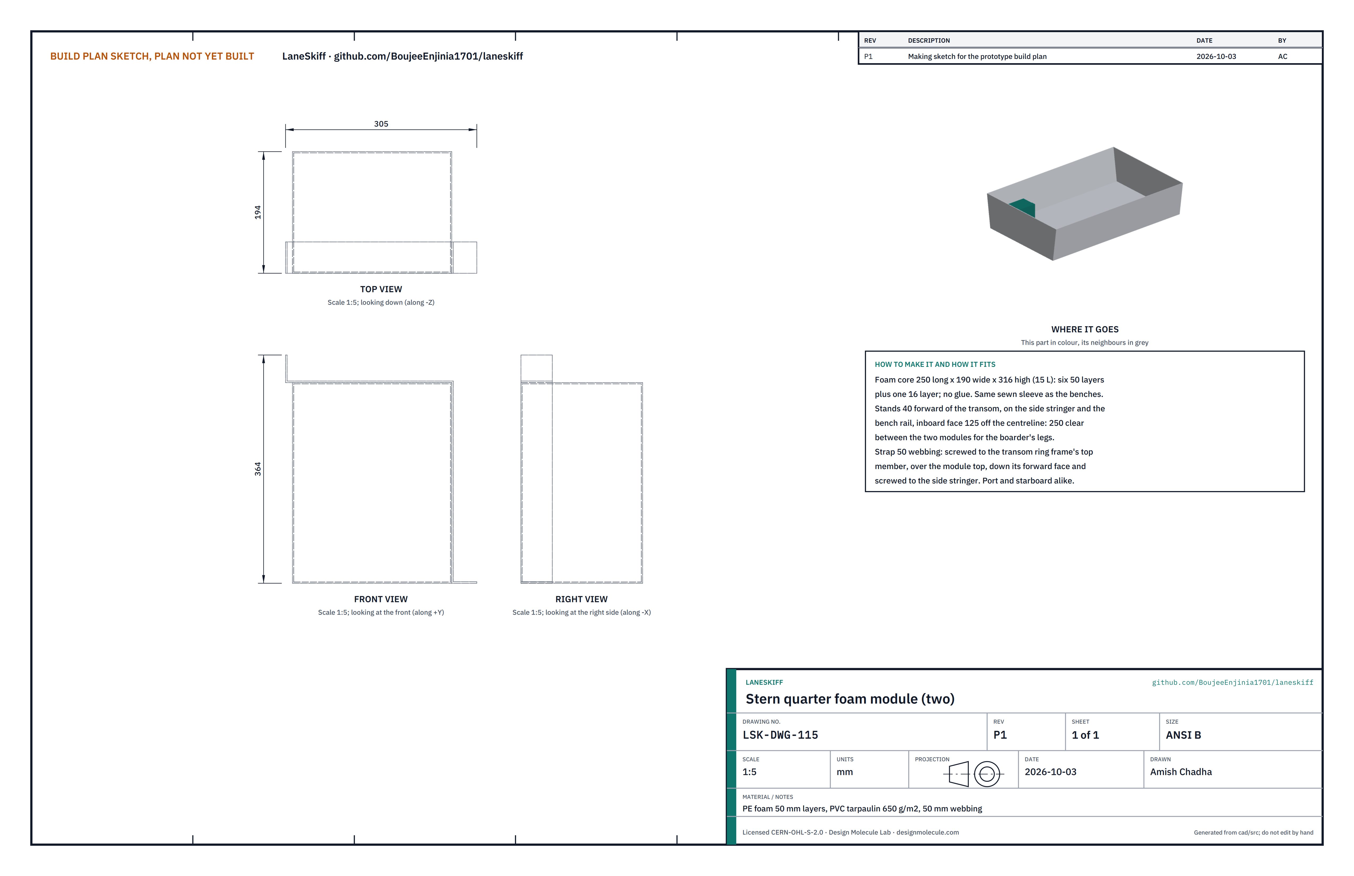
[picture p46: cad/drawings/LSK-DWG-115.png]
Making sketch: stern quarter foam module


**What it is and what it is made from.** Two modules, one each side of the step opening in the aft half. Each is a foam core 250 mm long, 190 mm wide and 316 mm high (15 litres: six 50 mm layers and one 16 mm layer of the same closed-cell polyethylene foam), in a sewn tarpaulin sleeve like the bench modules, held by one 50 mm webbing strap.

**How to make it.**

1. Cut the foam layers and stack them; no glue.
2. Sew the sleeve to the stack size; slide the stack in and lace the end.
3. Cut the strap about 750 mm long and heat-seal the ends.

**How it fits the parts next to it.** Each module stands 40 mm forward of the transom, on the side stringer and the bench rail, with its inboard face 125 mm from the centreline, so there is 250 mm of clear floor between the two modules for a boarder's legs. The strap is screwed to the inside face of the transom ring frame's top member, runs over the module and down its forward face, and is screwed to the top of the side stringer. The 40 mm gap at the transom keeps the module clear of the hinge rail bolt nuts.

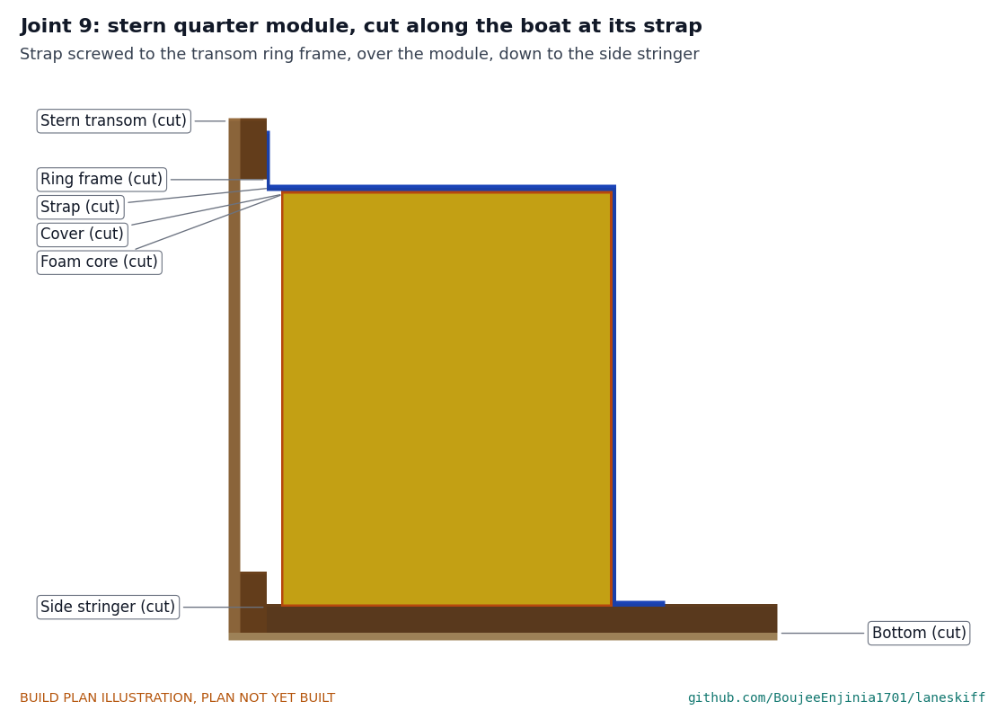
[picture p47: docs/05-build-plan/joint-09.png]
Stern quarter module, cut along the boat at its strap


*Figure 11. Stern quarter module on the side stringer, strapped to the transom ring frame and the stringer.*

**Check before moving on.** The module cannot be lifted by hand at its strap, and a boot passes between the two modules.

### 3.16 Bought components

- **Foam sheet:** closed-cell polyethylene, 2,000 x 1,000 x 50 mm, about 30 kg/m3; not polystyrene (fuel dissolves it) and not open-cell foam.
- **HDPE strip:** rub strakes 12 x 30 mm screwed through the side into the inwale every 200 mm; skids 40 x 8 mm screwed into the side stringers every 150 mm with 5 x 30 stainless screws, each hole bedded in sealant; the forward skids bend over the knuckle.
- **Joint bolts and nut plates:** M10 x 80 stainless A4-70 hex bolts with 30 mm washers; nut plates welded by a local welder and galvanised.
- **Hinges and pad eyes:** two heavy stainless strap hinges about 100 mm wide with 6 mm pins; four stainless pad eyes.
- **Webbing:** 25 mm polyester for the stop and rung straps, 50 mm for the bench and stern quarter module straps and the slings.
- **Handles:** two stainless tube grab handles about 250 mm long for the transom; eight grab handles about 200 mm long for the inwales, each with two M6 bolts.
- **Paddles, bow line and slings:** two 1.4 m paddles, 10 m of 10 mm polyester rope, two padded slings with snap hooks.

## 4. Putting it together

Each picture shows the parts already fitted in grey and the parts being fitted in colour, with an arrow showing the way they go in.

### Step 1: stitch the aft bottom and sides

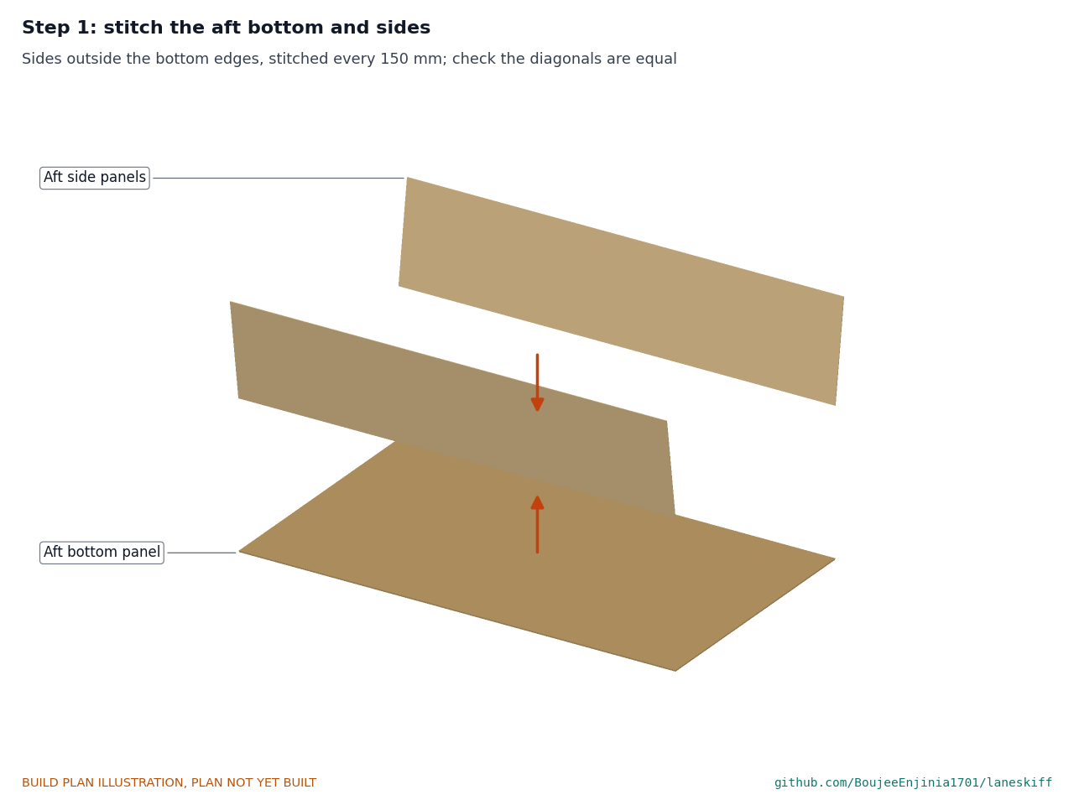
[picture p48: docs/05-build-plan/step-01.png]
Step 1


Stitch the side panels to the bottom with copper wire or cable ties every 150 mm. Check the diagonals are equal before any glue.

### Step 2: fit the stern transom and the aft joint bulkhead

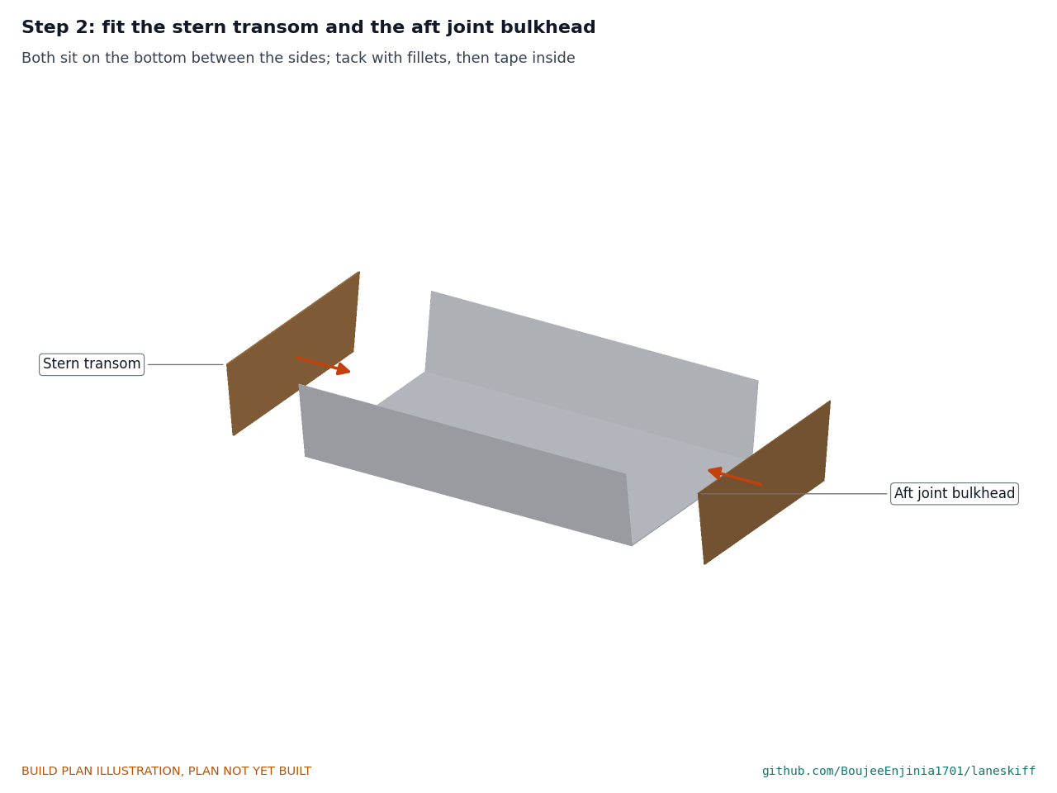
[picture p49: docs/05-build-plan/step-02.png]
Step 2


Both sit on the bottom between the sides. Tack with small fillets, check square, then fillet and tape every inside seam.

### Step 3: glue in the ring frames

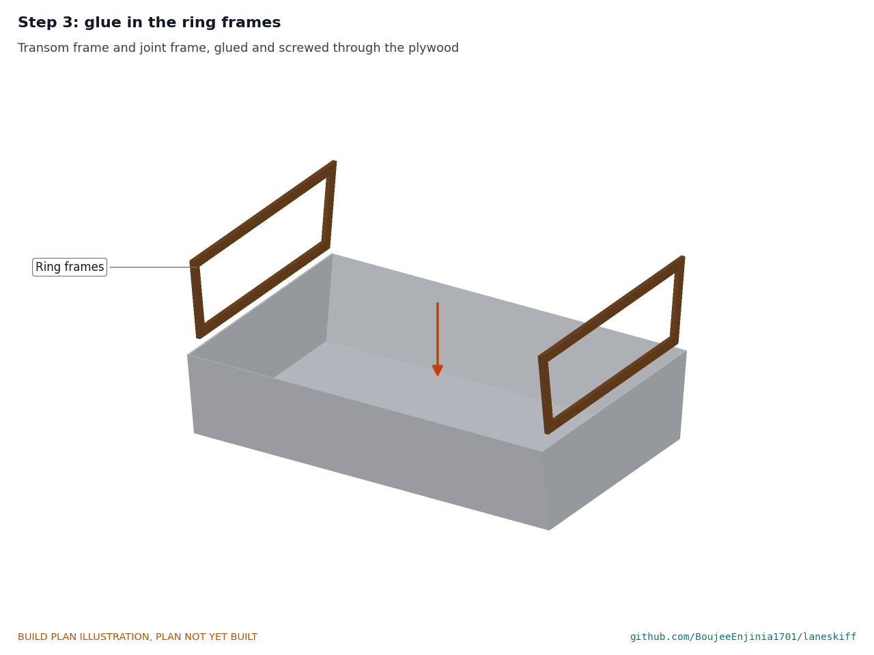
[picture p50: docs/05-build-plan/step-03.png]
Step 3


Glue and screw the transom frame and the aft joint frame. Hold point: let the epoxy cure before drilling.

### Step 4: fit the inwales

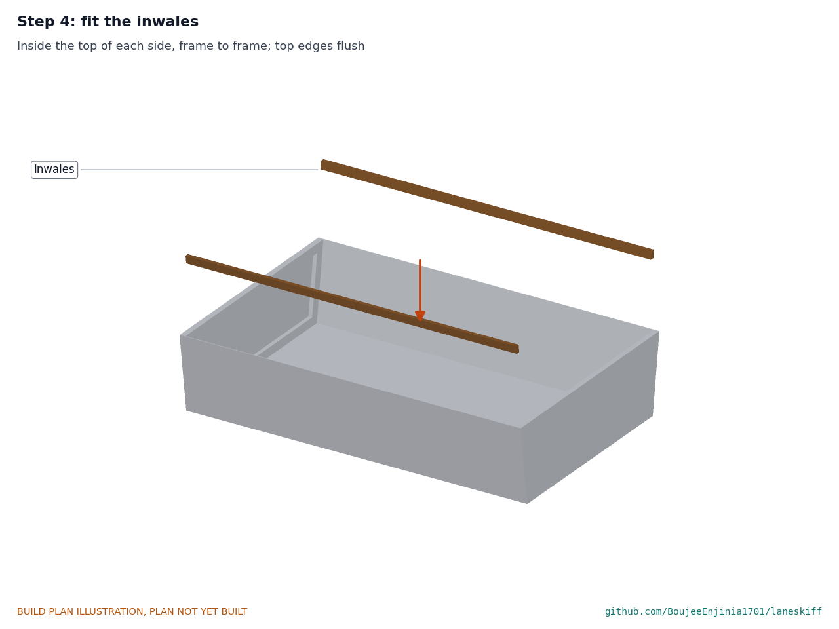
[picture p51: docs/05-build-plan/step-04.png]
Step 4


Glue and screw inside the top of each side, frame to frame.

### Step 5: glue down the stringers and bench rails

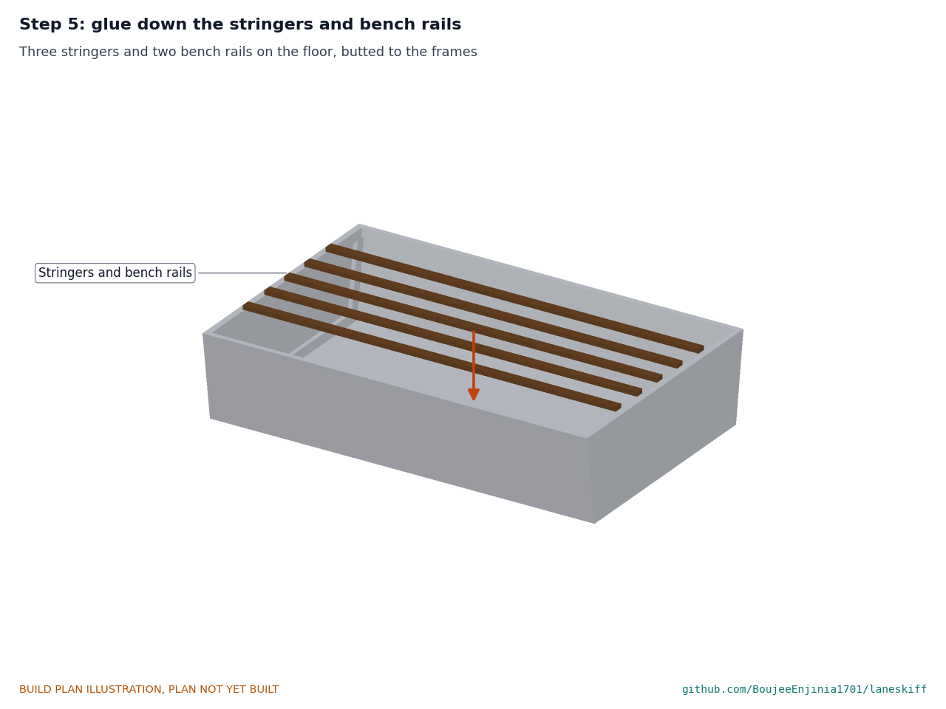
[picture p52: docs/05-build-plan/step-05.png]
Step 5


Three stringers and two bench rails on their marked lines.

### Step 6: glass the outside, then fit the skids and strakes

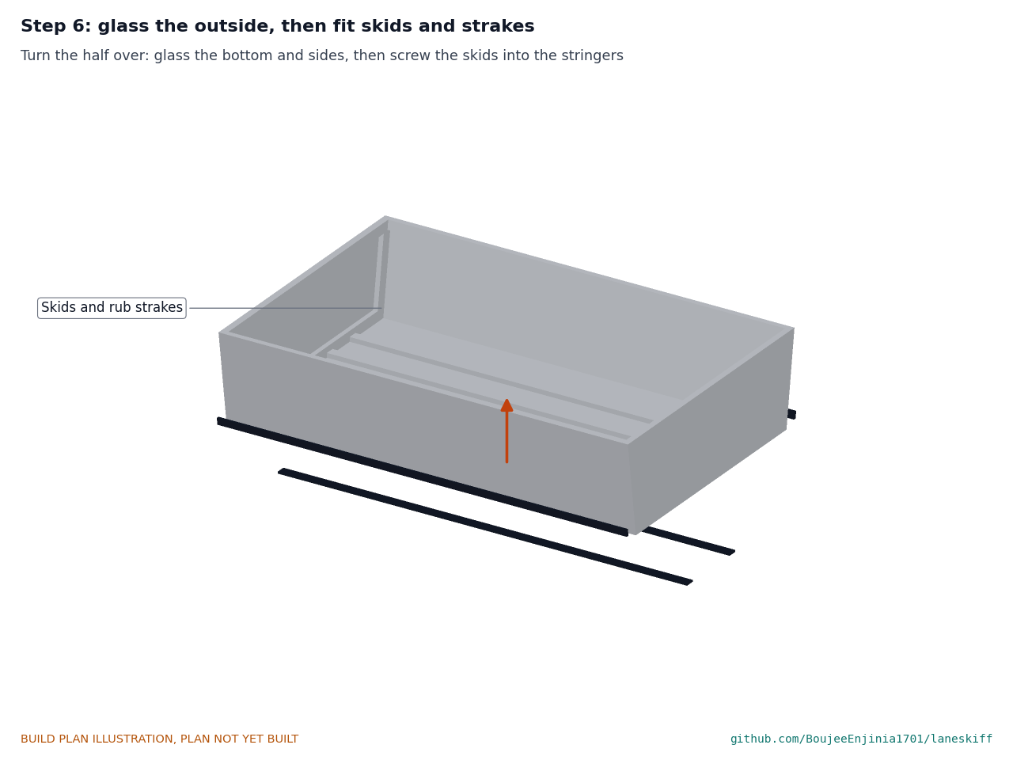
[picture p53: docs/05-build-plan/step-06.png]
Step 6


Turn the half over, remove the stitches, fill and round the chines, and glass the outside of the bottom and sides with 400 g/m2 cloth. The inside of the floor is not glassed. When cured, screw the skids into the side stringers and the rub strakes into the inwales, each hole bedded in sealant. Paint.

### Step 7: build the forward half the same way

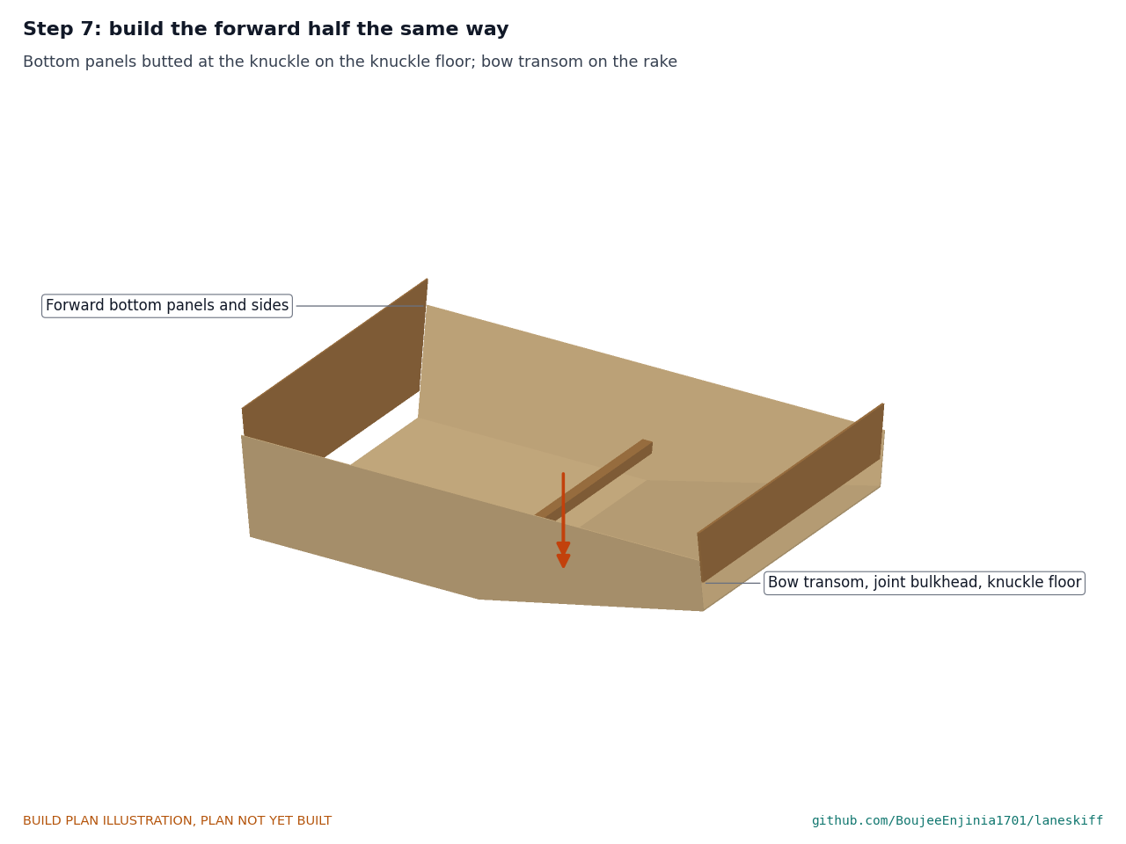
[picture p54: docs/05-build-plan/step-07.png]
Step 7


As steps 1 and 2, with the two bottom panels butted at the knuckle and the bow transom on the rake.

### Step 8: frame the forward half and close the bow box

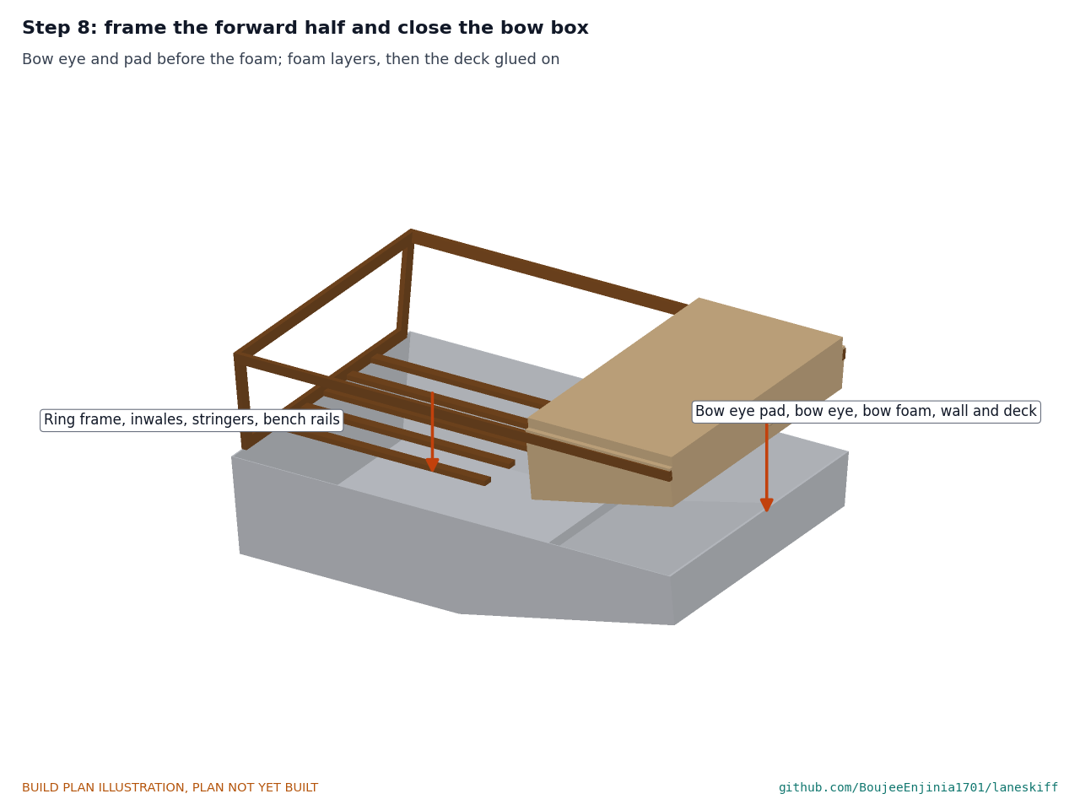
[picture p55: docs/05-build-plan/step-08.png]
Step 8


Ring frame, inwales, stringers and bench rails as on the aft half; then the bow eye and pad, the bow box wall, the foam and the deck.

### Step 9: glass, skids, strakes, bench modules and handles

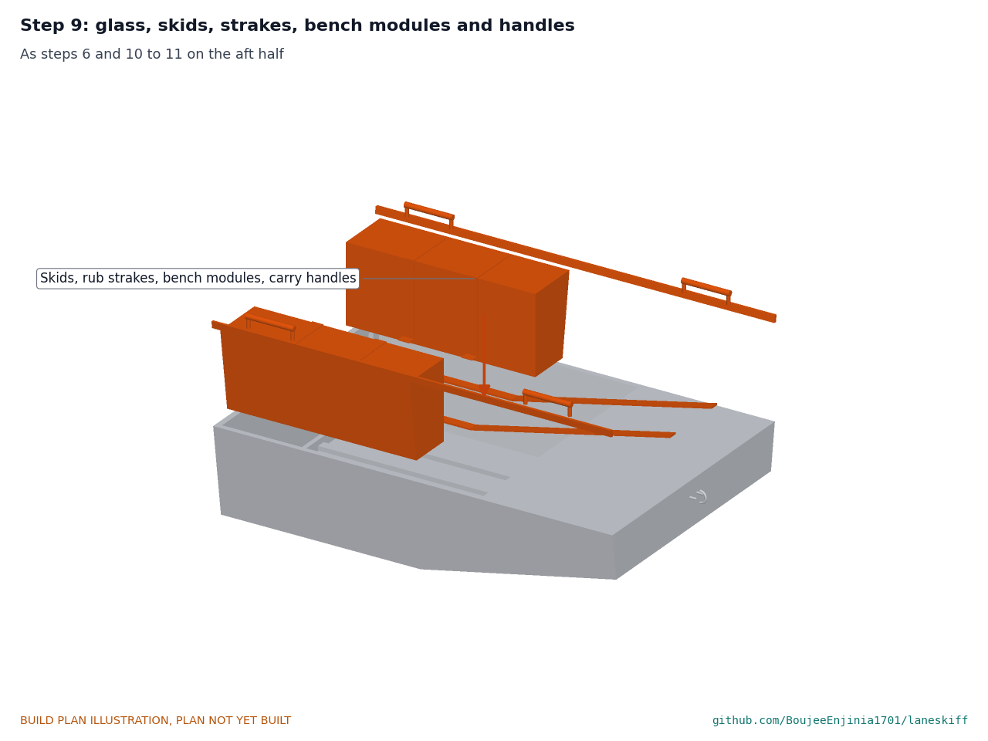
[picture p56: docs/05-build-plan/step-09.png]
Step 9


Finish the forward half as in steps 6, 10 and 11.

### Step 10: strap in the aft bench and stern quarter modules

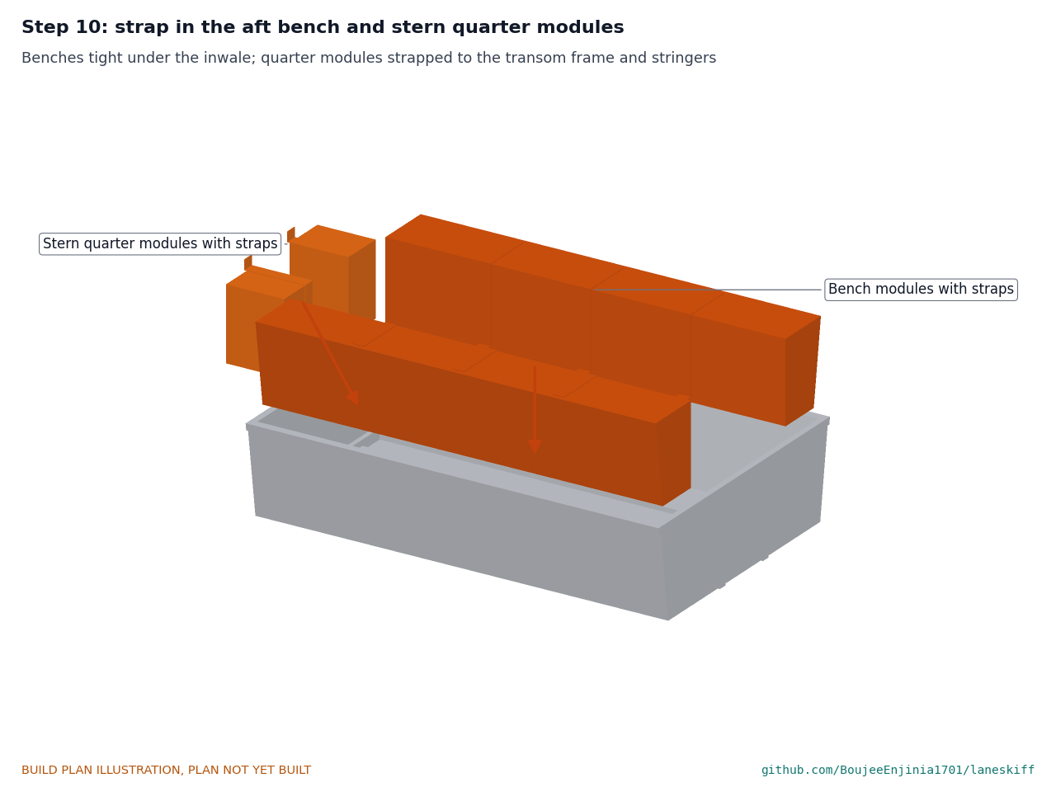
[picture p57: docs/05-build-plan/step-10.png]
Step 10


Slide each bench module under the inwale, against the side; screw each strap to the inwale and the bench rail, pulled snug. Then stand a stern quarter module either side of the step opening, 40 mm forward of the transom, and screw its strap to the transom ring frame and the side stringer.

### Step 11: fit the grab and carry handles

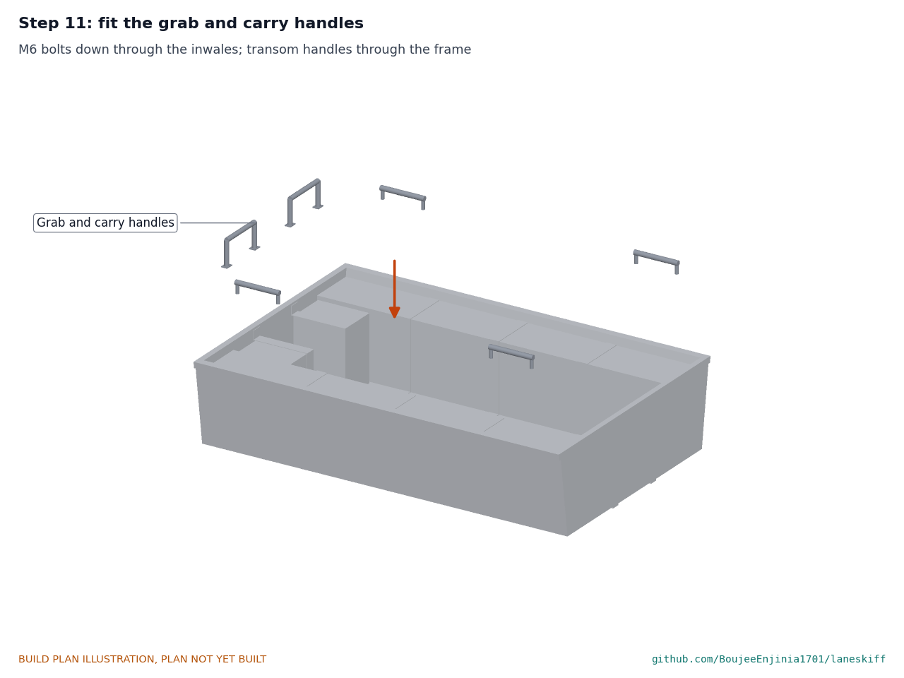
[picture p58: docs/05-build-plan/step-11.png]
Step 11


Carry handles with M6 bolts down through the inwales, two at each end of each half; transom grab handles through the transom and its ring frame.

### Step 12: bolt on the hinge rail

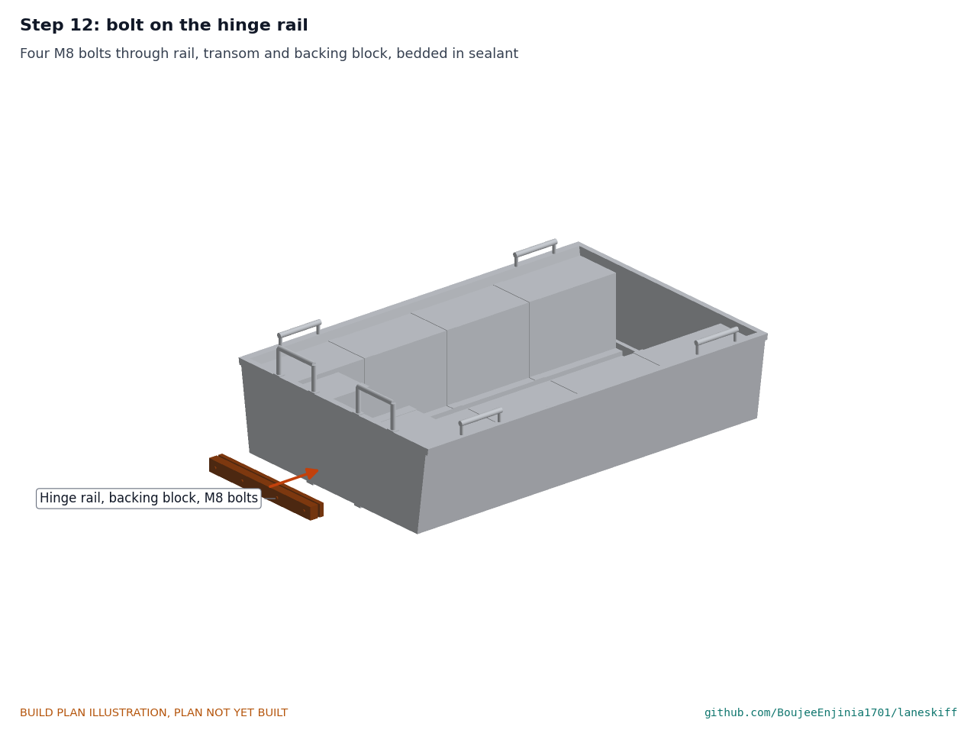
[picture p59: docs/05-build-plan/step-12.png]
Step 12


Four M8 bolts through rail, transom and backing block, bedded in sealant.

### Step 13: hang the step float

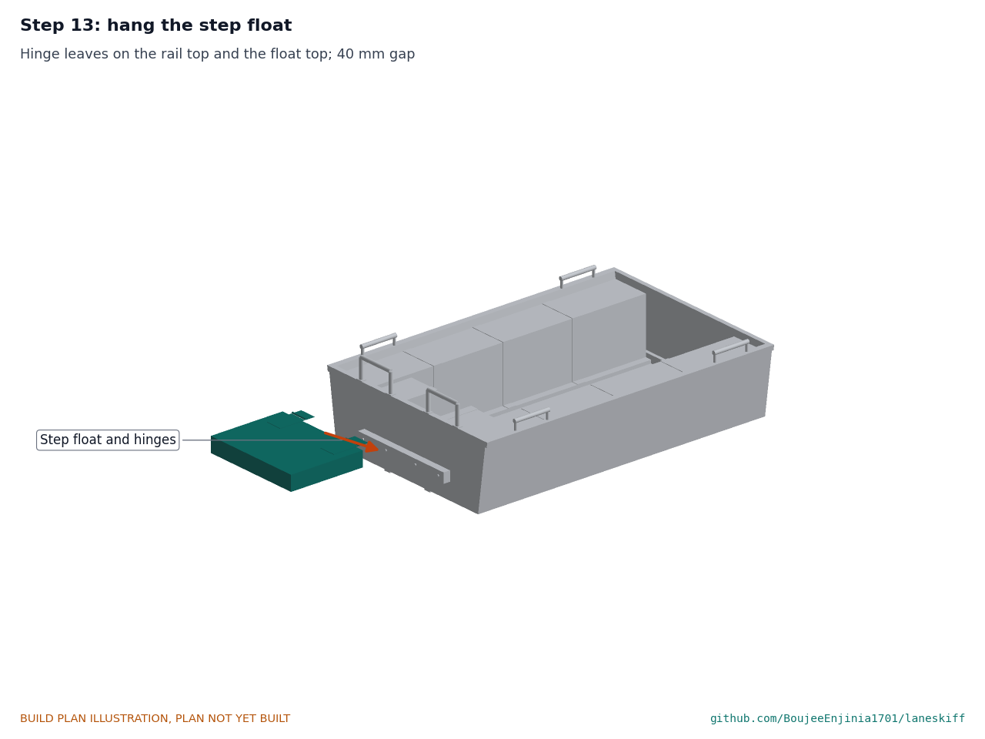
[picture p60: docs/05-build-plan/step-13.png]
Step 13


Screw the hinge leaves to the rail top and the float top with the 40 mm gap set by two spacer blocks; remove the blocks.

### Step 14: fit the stop straps and the kick rung

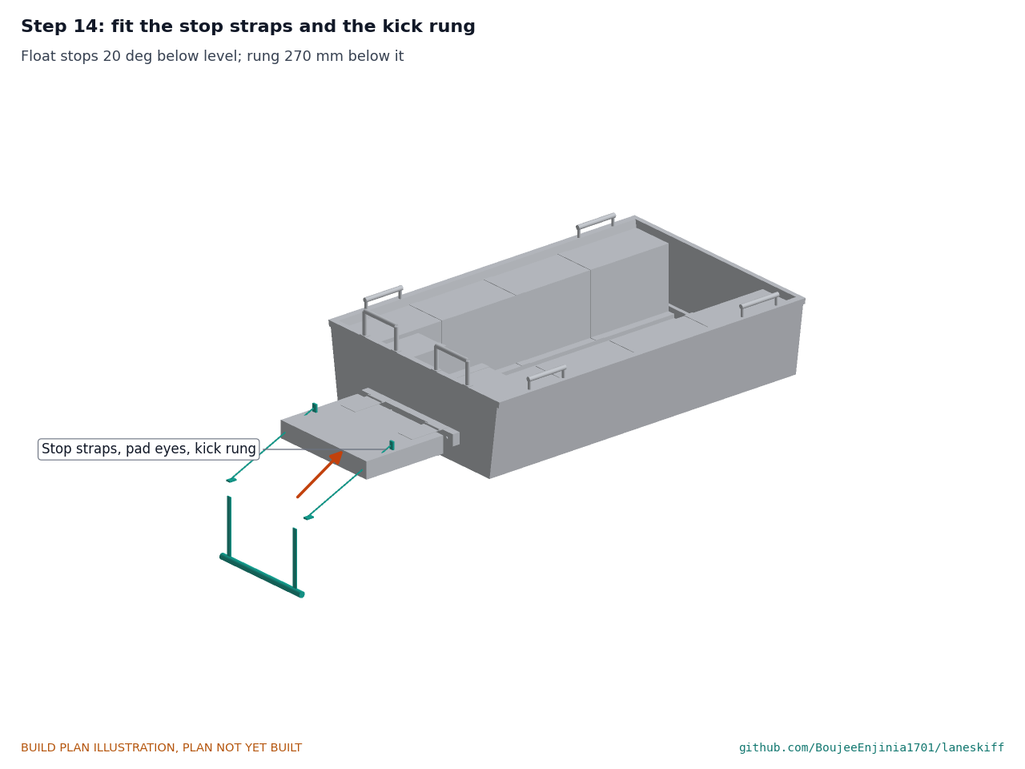
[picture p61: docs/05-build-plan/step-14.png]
Step 14


Pad eyes on the transom; adjust the straps so the float stops 20 degrees below level; hang the rung 270 mm below the float.

### Step 15: bring the halves together

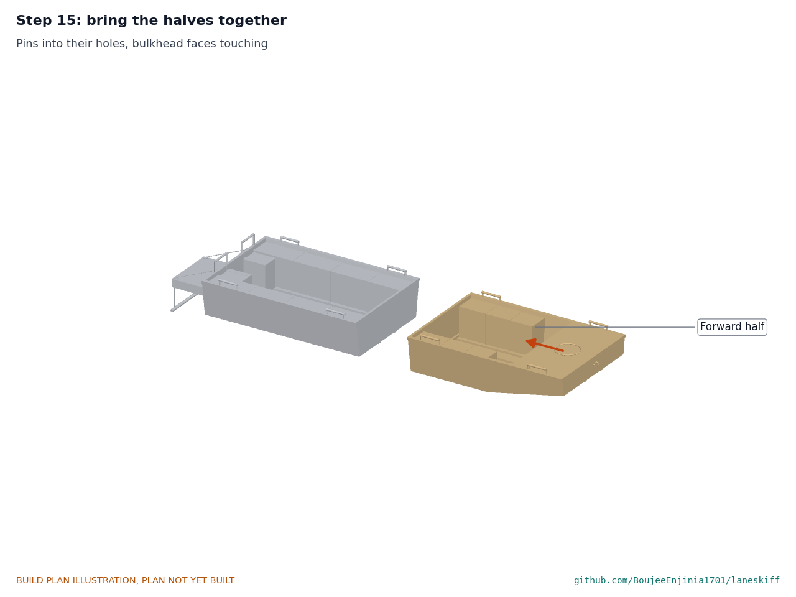
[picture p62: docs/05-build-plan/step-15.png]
Step 15


At the water's edge, stand the halves end to end, slide the pins into their holes and close the bulkhead faces together.

### Step 16: bolt the halves together

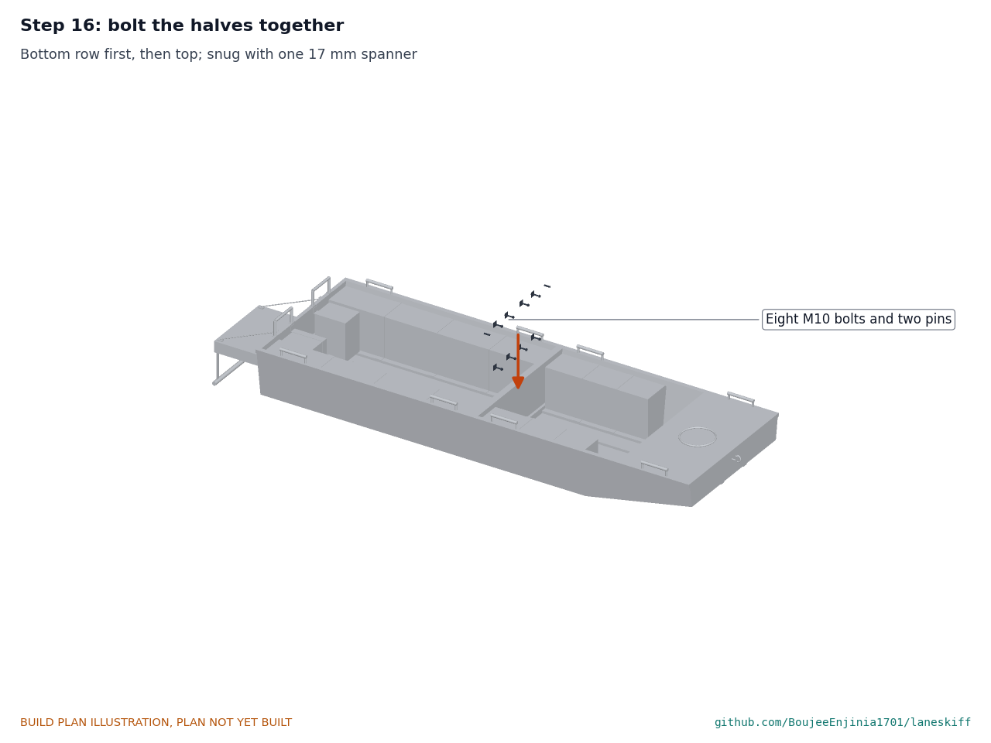
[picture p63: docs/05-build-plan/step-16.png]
Step 16


Bottom row first, then the top row, snugged with one 17 mm spanner from the forward side. Hold point: all eight bolts in before anyone steps in.

### Step 17: stow the pole, paddles and bow line

Step 17

Pole sections on the aft floor between the stringers, paddles on the aft benches, the bow line coiled on the bow deck and tied to the bow eye.

## 5. First checks

These are listed here and recorded in a TRL 4 test report.

*Table 2. First checks.*

| Check | Requirement | How | Pass when |
| --- | --- | --- | --- |
| Beam | R4 | Tape over the rub strakes; carry through a 1.3 m gate | Fits the gate without scraping |
| Carry mass | R1 | Weigh each half on a hanging scale | Recorded against LSK-CAL-001 (about 50 and 38 kg expected) |
| Joining the halves | R7 | Two people, one spanner, timed from halves on the ground to eight bolts tight | Joined, and within the R7 time |
| Each half alone | Safety | Float each half on its own in calm, shallow water | Floats upright, no leak at the bulkhead |
| Load and draft | R2, R3 | Water ballast in containers placed as the five rated persons, in calm water | Drafts recorded at the transom and bow (148 mm or less expected); no water over the gunwale |
| Swamp | R5 | Fill with water, ballast for the five rated persons at two thirds, following the ABYC H-8 procedure in a pool; once with the aft crew's ballast aft and once with it amidships (the aft-crew rule) | Floats, trim and freeboard recorded at the transom and bow for both |
| Boarding | R6 | Several volunteers of different builds board over the stern step from waist-deep water, inclinometer on the hull | Heel recorded; every volunteer boards unaided |
| Step proof load | R6, safety | Twice the working load on the float aft edge at its stop (CalRig) | No damage, no hinge or strap movement |

## 6. Safety stops

Work stops at each point below until what is listed is true.

- **Before anyone stands in the boat:** all eight joint bolts in and tight; every hull seam inspected, no dry fillets.
- **Before the first time on the water:** each half floated alone without a leak; the bow eye pulled to twice the towing load.
- **Before any boarding trial:** the step hinges, stop straps and kick rung proof-loaded to twice the working load (an 80 kg person kneeling on the float's aft edge with a factor of two); the hinge gap checked at 40 mm with nothing closing below 25 mm through the swing.
- **Before any load or swamp trial:** calm, shallow water no deeper than chest height, no current; a safety boat or bank team with a throw line; every person in a life jacket and briefed; ballast in place of people for the first swamp test.
- **Before any rescue use:** the TRL 4 trials passed, the five-person rating marked on the transom, and the crew trained under its own agency's rules, including the swamp drill: the aft crew member moves amidships and everyone sits low and centred. Never in moving water.

## 7. Tools, skills and workspace

- A covered, ventilated space about 5 x 3 m where epoxy can cure above 15 degrees Celsius, with two trestles.
- Jigsaw or circular saw, block plane, drill and drivers, a sanding block or orbital sander, clamps (twelve or more), mixing pots and fillet spatulas, a tape and long straightedge, a bevel gauge, a 17 mm spanner and a 13 mm spanner.
- Skills: stitch-and-glue boatbuilding (any small boatyard), basic sewing with a heavy machine or a sail maker for the covers and straps, and a welder for the nut plates.
- Gloves, eye protection and a dust mask for epoxy, glass and sanding.

## 8. Where the numbers come from

- Model: `cad/src/model.py` (dimensions, constructability checks), `cad/step/` and `cad/stl/`.
- Drawings: `cad/drawings/LSK-DWG-001` (general arrangement, Rev P3) and `LSK-DWG-101` to `115` (making sketches).
- Calculations: `docs/04-calcs/01-sizing.md` (LSK-CAL-001), `docs/04-calcs/sizing.py`, `docs/04-calcs/results.csv`.
- Bill of materials: `bom/bom.csv`.
- Pictures: `cad/src/build_plan_media.py`.
- Design changes: `docs/decisions/0002-design-for-construction.md` (LSK-DDR-002) and Amish's decisions of 2026-10-03, `docs/decisions/0003-amish-requirement-decisions.md` (LSK-DDR-003).

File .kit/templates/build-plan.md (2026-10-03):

---
doc_id: PRJ-BLD-001
title: Project prototype build plan
project: Project name
doc_type: Build plan
version: "0.1"
status: Draft
date: YYYY-MM-DD
author: Amish Chadha
license: CERN-OHL-S-2.0
revisions:
  - version: "0.1"
    date: YYYY-MM-DD
    author: Amish Chadha
    change: First build plan; design made constructable
---

# Project prototype build plan

**Plan, not yet built.** How to build the first proof-of-concept prototype, component by component. Building and testing to it is TRL 4 work. Decisions still to be made are kept in the design decisions register (`docs/06-design-decisions.md`), not here.

## 1. What you are building

Every component, pulled apart and numbered in build order

One short paragraph: what the prototype is, how many components, which are made and which are bought, and the main ways they are made.

## 2. What changed to make it buildable

| Component | The concept had | The buildable design has | Why |
| --- | --- | --- | --- |

## 3. Making the components

### 3.1 Component name

Making sketch

**What it is and what it is made from.**

**How to make it.**

1. Mark out ...
2. Cut ...

**How it fits the parts next to it.**

Close-up of the joint

**Check before moving on.**

## 4. Putting it together

### Step 1: ...

Step 1

## 5. First checks

| Check | Requirement | How | Pass when |
| --- | --- | --- | --- |

## 6. Safety stops

## 7. Tools, skills and workspace

## 8. Where the numbers come from

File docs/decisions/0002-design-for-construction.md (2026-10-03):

---
doc_id: LSK-DDR-002
title: LaneSkiff design for construction
project: LaneSkiff
doc_type: Design decision record
version: "0.1"
status: Draft
date: '2026-10-03'
author: Amish Chadha
license: CERN-OHL-S-2.0
revisions:
- version: "0.1"
  date: '2026-10-03'
  author: Amish Chadha
  change: Design made constructable; changes C1 to C13 and assumptions A1 to A6 decided under Amish's 2026-10-03 pre-approvals
---

# 0002: Design for construction

- **Date:** 2026-10-03
- **Status:** decided. Decided by Amish under his pre-approval of 2026-10-03: "start with the first 14 repos from the list of 29 projects. I pre-approve the batch runs along with any recommendations you come up with. I also accept any cost overruns or variations from the assumed scope cost." and, for this batch, "Proceed with the remaining 15 scaffolds".

## Context

STANDARDS section 18 asks that every part can be made by a stated process and fits and fastens to its neighbours. The concept named a hull "in two rigid halves that bolt together at a mid bulkhead", "closed buoyancy blocks under the side benches", "a hinged buoyant step" and handles, strakes and skids, but did not say how the panels join, what the bolts clamp, what holds the foam down when it lifts, or what stops the step. The constructability review of the model (`cad/src/model.py --check`, 73 checks: no overlap between any two parts; every part touching the part it is fixed to; every joint bolt through both ring frames and both bulkheads and clear of benches and stringers; rail bolts and bow eye through what they clamp; nothing but bolts and pins crossing the joint plane; the step float clear of the rail and transom at its 20 degree stop and when folded up; beam within 1.2 m) led to the changes below. All 73 checks pass. None changes what the product does, its pitch or its safety case.

## Changes

*Table 1. Changes made for construction.*

| # | The concept had | The constructable design has | Why |
| --- | --- | --- | --- |
| C1 | A hull massing shape | Stitch-and-glue panels: three bottom panels (aft, forward flat, bow rake) butting the inside of four flat side panels; transoms and bulkheads sitting on the bottom between the sides; epoxy fillets and glass tape on every seam | Every panel is flat and cut from a standard sheet; the bow rake is a separate panel joined at a knuckle |
| C2 | One mid bulkhead | Two 6 mm bulkheads, one closing each half, each with a hardwood ring frame 20 x 45 | Each half floats alone; the joint needs no seal; the frames give the bolts something to clamp |
| C3 | Bolts at the joint | Eight M10 x 80 stainless bolts from the forward side into nut plates (40 x 40 x 3 steel with a welded nut) screwed to the aft frame; two 12 mm alignment pins | One spanner joins the halves (R7); the plate spreads the load into the hardwood (factor 5 in the kerb case) |
| C4 | Buoyancy blocks under side benches | Foam modules in sewn tarpaulin covers (the LevelHull module), outboard from 330 mm off the centreline to the side, top touching the inwale; held by the inwale and by webbing straps screwed to the inwale and to a hardwood bench rail on the floor | Plywood bench boxes would have added about 9 kg; the inwale and straps carry the swamped lift; the cover protects the foam |
| C5 | Buoyancy in the bow | A bow box: 6 mm wall at 3.0 m, 6 mm deck, foam layers cut to the rake | Puts foam forward and high; the deck is a dry place for the bow line |
| C6 | A flat floor | Three hardwood stringers 40 x 20 per half (centreline and 150 mm each side), bench rails, and a knuckle floor across the boat | Largest floor span 160 mm (factor 1.5 on a foot load); the skids screw into the side stringers; the knuckle floor joins the two bottom slopes |
| C7 | Sheer edge | Hardwood inwales 20 x 40 inside the top of each side, frame to frame | Stiffen the sheer; carry the handle bolts, the strake screws and the bench module tops |
| C8 | A hinged buoyant step | Hardwood hinge rail 40 x 60 on the transom, bolted through a backing block with four M8 bolts; a float 450 x 600 x 90 (hardwood rim, plywood decks, foam core); two strap hinges across a 40 mm gap; stop straps to transom pad eyes at 20 deg below level; kick rung 270 mm below on webbing | The float swings without trapping fingers or feet (checked at the stop and folded up); the straps take the kneeling load (factor 4.2) |
| C9 | Stern transom and bulkheads (thickness not set) | Transom 9 mm with a ring frame; bulkheads 6 mm with ring frames; bow transom 9 mm | The frames carry the loads; thinner plywood saves mass |
| C10 | Rub strakes and skids | HDPE strakes 12 x 30 screwed through the side into the inwale; HDPE skids 40 x 8 screwed into the side stringers, the forward pair bent over the knuckle | Every screw lands in hardwood, never in 6 mm plywood alone |
| C11 | Carry handles and yoke points | Eight bought grab handles bolted through the inwales, two at each end of each half; padded shoulder slings clip to them; transom grab handles bolted through the transom ring frame | Each half has its own four handles; no separate yoke fittings |
| C12 | Push pole | Two 1.5 m aluminium sections with a sleeve, stowed on the aft floor between the stringers; paddles on the aft bench tops | Nothing stowed crosses the joint |
| C13 | Bow line point | Stainless U-bolt through the bow transom and a hardwood pad, nuts inside, fitted before the bow foam | Tow and doorway line; the pad spreads the load |

## Assumptions

*Table 2. Assumptions decided with the changes.*

| # | Assumption | What would change it |
| --- | --- | --- |
| A1 | Marine plywood about 600 kg/m3, hardwood about 700 kg/m3 | Weighing the sheets and timber bought; lighter stock lowers the hull mass (see the R1 options) |
| A2 | Closed-cell polyethylene foam 30 kg/m3, under 1 % water uptake by volume | Supplier data sheet, then 30 days immersion of samples |
| A3 | Persons count at two thirds of their weight when swamped (conservative) | The ABYC H-8 procedure swamp test |
| A4 | Hinges, webbing and nut plates at the strengths in LSK-CAL-001, table 1 | Proof load of the step and joint before trials (CalRig) |
| A5 | The 40 mm hinge gap is wide enough to keep fingers and feet clear | A pinch check with test fingers and a boot at TRL 4; never narrowed without it |
| A6 | Epoxy and glass at the rates in LSK-CAL-001, A5 | Weighing the first half after glassing |

## Consequences

- The hull is 100 kg as built (LSK-CAL-001). The changes added hardwood and fixings that the massing model did not have, and removed about 9 kg by using covered foam modules in place of plywood bench boxes.
- Requirements not met or at risk (R1, R2, R3, R5, R10) are set out for Amish in `docs/REVIEW.md`; nothing in this record decides them.
- STEP and STL files, the general arrangement (LSK-DWG-001, Rev P2), the making sketches (LSK-DWG-101 to 114), the concept media and the build plan (LSK-BLD-001) are generated from the changed model.

## Safety

> **Safety:** C3, C8 and C13 carry people's weight or a tow; each is proof-loaded to twice its working load before trials (LSK-BLD-001, safety stops). C8's 40 mm gap and 20 degree stop are conservative; they are kept until a pinch check and boarding trials show a closer gap is safe.

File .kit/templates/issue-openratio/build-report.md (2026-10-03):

---
name: Build report
about: Tell us what happened when you built, printed or tested part of this design
title: "Build report: "
labels: build-report
---

This is a research and educational prototype, not a medical device. It is a TRL 3 concept and is not released for fabrication. If you build any part of it, you do so at your own risk. Reports help everyone.

**What you built** (part, sub-assembly or test)

**Materials, tools and settings**

**What worked**

**What did not work, with photos or measurements if you have them**

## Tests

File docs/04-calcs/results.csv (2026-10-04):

tag | item | value | unit | requirement | status
M1 | Hull mass, complete, plywood and epoxy path, light specification (step, handles and strakes included; pole, paddles, line not) | 87.9 | kg | R1 | Not met
M2 | Aft half mass, with the stern step | 49.9 | kg | R1 | Not met
M3 | Forward half mass | 38.1 | kg | R1 | Not met
M4ply | Mass of okoume plywood | 24.8 | kg
M4sw | Mass of softwood framing | 12.8 | kg
M4hw | Mass of hardwood (step, pad, rung) | 4.2 | kg
M4foam | Mass of foam | 18.3 | kg
M4hdpe | Mass of HDPE strakes and skids | 4.7 | kg
M4steel | Mass of bolts and bow eye | 1.3 | kg
M4fabric | Mass of bench covers and straps | 5.1 | kg
M4bought | Mass of bought fittings | 4.3 | kg
M5 | Glass, epoxy, coating, tapes and small fixings | 12.4 | kg
M6 | Loose gear: pole, two paddles, bow line | 6.2 | kg
M7 | Hull LCG from the transom; KG above the outside of the bottom | 1556; 177 | mm
M8 | Plywood areas: bottom; sides; other panels | 3.82; 2.73; 3.09 | m2
L1 | Rated load: a crew of two and three adults at 75 kg (five persons) | 375 | kg
L2 | Rated load over hull mass | 4.26 |  | R2 | Not met
H1 | Draft at rated load, even keel (outside of the bottom) | 143 | mm
H2 | Trim at rated load (+ = stern down); draft at the transom; draft at the forward end of the waterline | 0.16; 148; 138 | deg; mm; mm | R3 | Met
H3 | Freeboard at rated load, lowest (transom) | 252 | mm
H4 | Waterline length and beam at rated load | 3.34; 1.10 | m
H5 | Transverse metacentric height GM at rated load | 0.31 | m
H6 | Load to sink 10 mm at rated draft | 36.8 | kg
H7 | Load carried at 150 mm draft, even keel | 401 | kg
H8 | That load over hull mass | 4.56
H9 | Draft with the crew of two only | 79 | mm
B1 | Heel, 80 kg boarder on the stern step, 150 mm off the centreline | 3.3 | deg | R6 | Met
B2 | Trim and transom freeboard while boarding over the stern | 0.7; 279 | deg; mm
B3 | For comparison, heel with the same boarder over the side, at the gunwale | 12.8 | deg
B4 | Low-side freeboard with the side boarder | 164 | mm
F1 | Buoyancy foam in the hull (benches, bow box and stern quarter modules) | 0.592 | m3
F2 | Swamped, rated persons aboard: water level inside and out, above the outside of the bottom | 224 | mm
F3 | Swamped: weight carried by the foam (persons at two thirds) | 307 | kg
F4 | Swamped trim (+ = stern down) | 0.42 | deg
F5 | Swamped freeboard at the transom and at the bow | 161; 188 | mm | R5 | Met on paper
F6 | Swamped transverse GM | 0.56 | m
F7 | Swamped heel with two seated persons moving 400 mm to one side | 13.1 | deg
F8 | Swamped low-side freeboard in that case | 39 | mm
F9 | Foam needed for zero freeboard, rated persons, as a share of the fitted foam | 0.49
S1 | Floor: largest clear span between stringers and bench faces | 160 | mm
S2 | Floor bending stress under a 1.2 kN foot load (plywood only, glass ignored) | 26.7 | MPa
S3 | Floor factor against plywood bending strength | 1.5
S4 | Joint: hogging over a kerb at the joint, rated load, top bolt tension each | 2.7 | kN
S5 | Joint bolt factor (bolt proof; nut plate bearing) | 10.7; 5.9
S6 | Step: pull in each stop strap, 80 kg kneeling on the aft edge, dynamic factor 2 | 1.88 | kN
S7 | Stop strap factor against webbing strength | 4.2
S8 | Hinge load each (upper bound), and factor | 2.67; 1.5 | kN
T1 | Joining the halves: place and align 2 min, eight bolts at 25 s, check 1 min (estimate) | 6.2 | min | R7 | Met on paper (estimate)
P1 | Build path: Plywood and epoxy; hull mass; load at 150 mm draft; ratio | 88; 401; 4.6 | kg; kg; - | R8 | Met on paper (three paths documented)
P2 | Build path: Aluminium 5052 sheet, welded or riveted; hull mass; load at 150 mm draft; ratio | 101; 388; 3.8 | kg; kg; -
P3 | Build path: HDPE or polypropylene sheet, plastic welded; hull mass; load at 150 mm draft; ratio | 111; 377; 3.4 | kg; kg; -
D1 | Six persons (450 kg) in the decided design, for comparison: deepest draft; over hull mass | 177; 5.12 | mm; -
D2 | Hull mass at which the five-person rated load is 6 times hull mass | 62.5 | kg
D3 | Load carried at 150 mm draft over hull mass (as H8) | 4.56
F10 | Swamped, with the aft-crew rule (aft crew moves amidships): trim; freeboard at the transom; at the bow | -1.19; 216; 141 | deg; mm; mm | R5 | Met on paper
F11 | Of the foam in F1, the two stern quarter modules | 30.0 | L
C1 | Estimated cost of the constructable design (bom/bom.csv) | 1961 | USD | R9 | Over the value-engineering target by USD 461
R10 | Fin drive | not designed in the first prototype |  | R10 | Not shown on paper

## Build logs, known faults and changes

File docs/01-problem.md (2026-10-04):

---
doc_id: LSK-PRB-001
title: LaneSkiff problem statement
project: LaneSkiff
doc_type: Problem statement
version: "0.3"
status: Draft
date: '2026-10-03'
author: Amish Chadha
license: CERN-OHL-S-2.0
revisions:
- version: "0.1"
  date: '2026-09-30'
  author: Amish Chadha
  change: Initial scaffold
- version: "0.2"
  date: '2026-10-03'
  author: Amish Chadha
  change: Budget stated as a value-engineering target; open questions answered at TRL 3; first co-design candidates; safety section
- version: "0.3"
  date: '2026-10-03'
  author: Amish Chadha
  change: Open question answers updated for Amish's decisions of 2026-10-03 (LSK-DDR-003)
---

# LaneSkiff problem statement

Floods strand people in narrow lanes and low houses where big boats cannot go. The small boats that can go there are hard to carry, easy to tip, and hard to climb into from waist-deep water.

## The problem

Most flood deaths are drownings ([WHO](https://www.who.int/health-topics/floods/drowning---key-facts)), and most flood-exposed people live in low and middle income countries ([Rentschler et al., 2022](https://www.nature.com/articles/s41467-022-30727-4)). In the first hours, rescue is done by local fishers, volunteers and whatever boats are nearby, as in Kerala in 2018 ([The Week, 2018](https://www.theweek.in/news/india/2018/08/20/kerala-fisherman-turns-stepping-stone-to-safety-literally.html)) and Houston in 2017 ([NBC News, 2017](https://www.nbcnews.com/storyline/hurricane-harvey/triumph-struggle-ragtag-cajun-navy-responds-houston-flood-n796991)). Boarding is the weak point: a person in waist-deep water has to lift their own weight over a side that tips toward them.

Existing craft solve parts of the problem. Inflatable rescue craft are light and buoyant but cost USD 4,900 ([Oceanid](https://oceanid.com/RDC-Pricing-Specifications.html)). Jon boats are cheap and flat but rated for two ([Lund](https://www.lundboats.com/families/jon-boat/1240.html)). Folding boats such as the Porta-Bote Alpha 12 carry three people and weigh 127 lb (58 kg) assembled ([Porta-Bote](https://portabote.com/product/alpha-series-12/)). The patented emergency watercraft of US7832348B2 carries about 30 people on inflatable pontoons behind a personal watercraft ([Google Patents](https://patents.google.com/patent/US7832348B2/en)), which needs an engine and a PWC. Small boats under 20 ft are expected to float level when swamped ([New Boat Builders](https://newboatbuilders.com/pages/flot.html); [ABYC H-8](https://webstore.ansi.org/standards/abyc/abyc2022-2483768)). No open design combines a carry-in hull, a stable stern boarding step, level swamped flotation and local build paths.

## Users and context

| User | Need | Context |
| --- | --- | --- |
| Community rescuers (fishers, volunteers) | A boat two people can carry into a lane and pole along, that people can board from the water | First hours of a flood, before or alongside official teams |
| Civil defence and disaster response teams | A light, cheap craft to add to heavier boats for lane work | Urban and village floods; transport by pickup or small truck |
| People being rescued, including older adults, children and people with limited mobility | A stable step and handholds to climb in without help from below | Standing in waist-deep water or at a doorway or window |
| Local boatbuilders | Drawings and a material table they can build from with local sheet and timber | Small yards building before the monsoon season |

## Operating environment

- Floodwater in lanes and streets, typically knee to chest deep, with debris, submerged walls, kerbs and drains.
- Lanes and doorways about 1.2 m wide or more (estimate of the target envelope).
- Mostly slow-moving water; not designed for swiftwater or open water.
- Heat, rain and night work; boats stored for months between floods.

## Constraints

- Value-engineering target for the prototype: USD 1,500 (a hypothetical control target, not a spending limit; STANDARDS section 18).
- Carried by two people: about 40 to 50 kg total carry mass (estimate from the preliminary screen), in two halves.
- Payload 5 to 8 times hull mass (a rigid hull; 10 times is not realistic).
- Single flat hull, poled or paddled; no twin pontoons, jet ski transom or hinged bow ramp.
- Two rigid halves that bolt together; no flexible panel hull or folding transom.
- Optional fin drive fixed and forward-only, with no reverse mechanism.
- Hardware under CERN-OHL-S-2.0; any software or calculation scripts under MIT.

## Out of scope

- Swiftwater, surf or open-water rescue.
- Outboard engines and powered propulsion other than the optional fin drive.
- Inflatable sponsons in the first version.
- Certification as a rescue boat or to CE or USCG standards at this TRL.
- Rescue training; users must follow their own agency's water rescue training.

## Prior work

| Prior work | What it does | Gap for these users | Source |
| --- | --- | --- | --- |
| Oceanid RDC rapid deployment craft | Inflatable rescue craft, 15 ft 4 in, 50 lb, more than 2,000 lb buoyancy, USD 4,900 | Costly and imported; no stable boarding step for people in the water | [link](https://oceanid.com/RDC-Pricing-Specifications.html) |
| Lund 1240 jon boat | 12 ft flat-bottom aluminium boat, 107 lb, 535 lb load, from USD 1,694 | Rated for two people; side boarding tips the boat | [link](https://www.lundboats.com/families/jon-boat/1240.html) |
| MetalBoatKits 19 ft Flood Rescue Skiff | Aluminium kit boat for eight people, hull about 245 kg, 8 in draft at full load | Far too heavy to carry into a lane; needs an outboard | [link](https://metalboatkits.com/product/19-foot-6m-flood-rescue-skiff-new/) |
| Porta-Bote Alpha Series 12 | Folding boat, 12.2 ft, 127 lb assembled, 3 people, 555 lb load | Low capacity for rescue; folding hull covered by live Porta-Bote patents | [link](https://portabote.com/product/alpha-series-12/) |
| US7832348B2, emergency watercraft (Newcomb) | Twin inflatable pontoons with a floor, hinged ramp and a transom for a personal watercraft; about 30 people; anticipated expiry 2028 | Needs a PWC and a large crew to assemble; live patent LaneSkiff avoids | [link](https://patents.google.com/patent/US7832348B2/en) |
| US6932020B2, boat boarding device (expired 2013) | Hinged floating platform with flotation and a step for swimmers to board | Recreational add-on; free prior art LaneSkiff builds on for its stern step | [link](https://patents.google.com/patent/US6932020B2/en) |

## Co-design

A coastal fishing community or volunteer rescue group with flood rescue experience, working with a local boatyard, in a flood-prone state such as Kerala or Bihar, so the step, carry handles and material choices are shaped by people who have done lane rescues.

First candidates to approach (none approached yet, nothing agreed; LSK-DDR-001, D9):

- [ ] A fishers' volunteer rescue group in Malappuram district, Kerala, with a boatyard on the same coast that builds plywood and epoxy boats.
- [ ] Country boat makers in a flood-prone district of north Bihar, for the timber and local-material build path.
- [ ] A state disaster response force or civil defence training unit, for the boarding and swamp trials.

## Open questions

The TRL 1 questions are answered on paper at TRL 3 (LSK-CAL-001, LSK-DDR-001); the answers are confirmed by trials at TRL 4.

- **Best build material for Kerala and Bihar?** Plywood and epoxy, stitch and glue, for the first prototype: the most widely available skills and materials, and repairable. Aluminium and HDPE paths come out at similar mass (LSK-CAL-001, section 8).
- **Step depth and folding for children and older adults?** A float that lies on the water behind the transom, with a kick rung 270 mm below it, and two transom handles; a person steps on the rung, kneels on the float and rolls over the transom. The float folds up against the transom for carrying.
- **Level swamped flotation inside the weight budget?** Level flotation works with 0.59 m3 of foam (18 kg) placed outboard, forward and in the stern quarters, but the hull comes out at 87.9 kg in the light timber specification against the 50 kg target; Amish accepted this on 2026-10-03 (LSK-DDR-003).
- **Is the fin drive worth it?** Not in the first prototype: Amish decided on 2026-10-03 to leave it out (LSK-DDR-003); an open fixed forward-only drive stays a later idea for the portfolio.
- **Which partner hosts the first trials?** The first candidates above, to approach.

> **Safety:** Flood water is dangerous even when it looks calm: submerged walls, open drains and manholes, live electrical wires, debris and contaminated water. LaneSkiff is not for swiftwater, surf, open water or water flowing faster than a person can wade against. Crew and passengers wear life jackets at all times, crews follow their own agency's water rescue training, and the boat is an open engineering reference, not certified rescue equipment.

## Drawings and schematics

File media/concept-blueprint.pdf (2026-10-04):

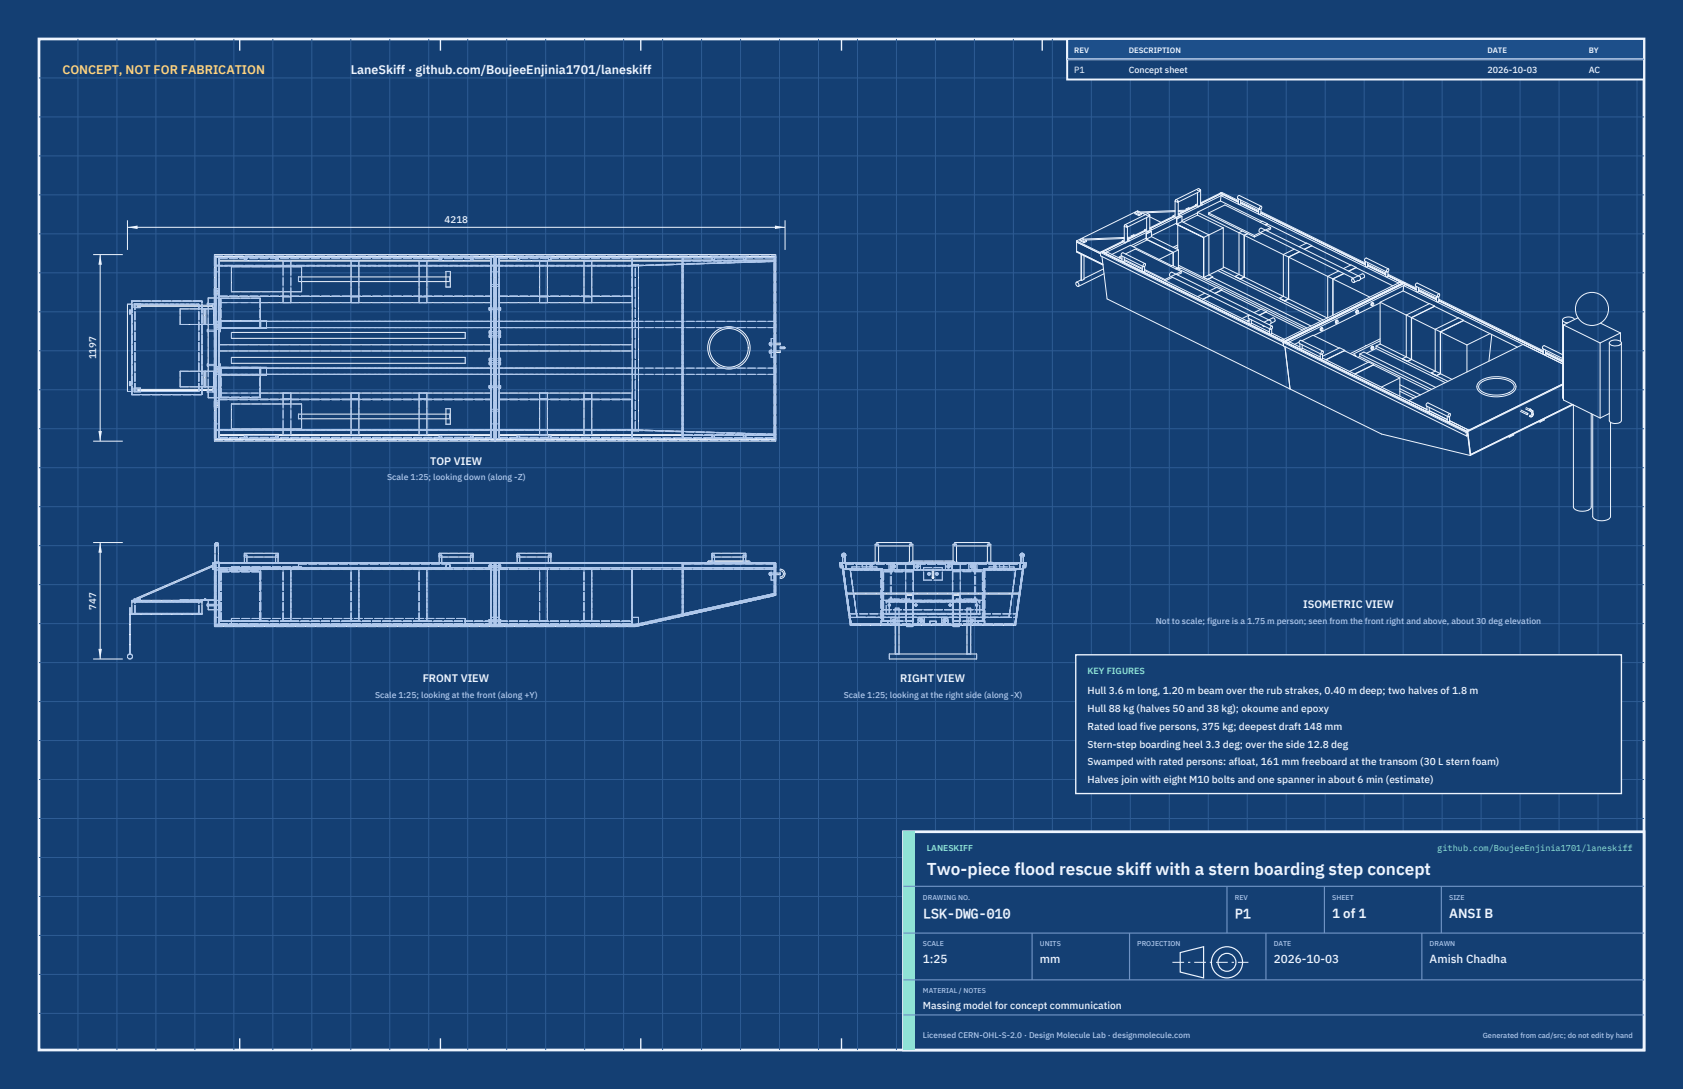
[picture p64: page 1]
CONCEPT, NOT FOR FABRICATION; LaneSkiff · github.com/BoujeeEnjinia1701/laneskiff; FRONT VIEW; TOP VIEW; RIGHT VIEW; ISOMETRIC VIEW; REV; DESCRIPTION; DATE; Concept sheet; LANESKIFF; github.com/BoujeeEnjinia1701/laneskiff; DRAWING NO. LSK-DWG-010; REV P1; SHEET 1 of 1; SIZE ANSI B; SCALE 1:25; UNITS mm; PROJECTION; DRAWN Amish Chadha; Licensed CERN-OHL-S-2.0 · Design Molecule Lab · designmolecule.com; Generated from cad/src; do not edit by hand

Scale 1:25; looking down (along -Z)

Not to scale; figure is a 1.75 m person; seen from the front right and above, about 30 deg elevation

KEY FIGURES
Hull 3.6 m long, 1.20 m beam over the rub strakes, 0.40 m deep; two halves of 1.8 m
Hull 88 kg (halves 50 and 38 kg); okoume and epoxy
Rated load five persons, 375 kg; deepest draft 148 mm
Stern-step boarding heel 3.3 deg; over the side 12.8 deg
Swamped with rated persons: afloat, 161 mm freeboard at the transom (30 L stern foam)
Halves join with eight M10 bolts and one spanner in about 6 min (estimate)

Scale 1:25; looking at the front (along +Y)

Scale 1:25; looking at the right side (along -X)

Two-piece flood rescue skiff with a stern boarding step concept

MATERIAL / NOTES
Massing model for concept communication

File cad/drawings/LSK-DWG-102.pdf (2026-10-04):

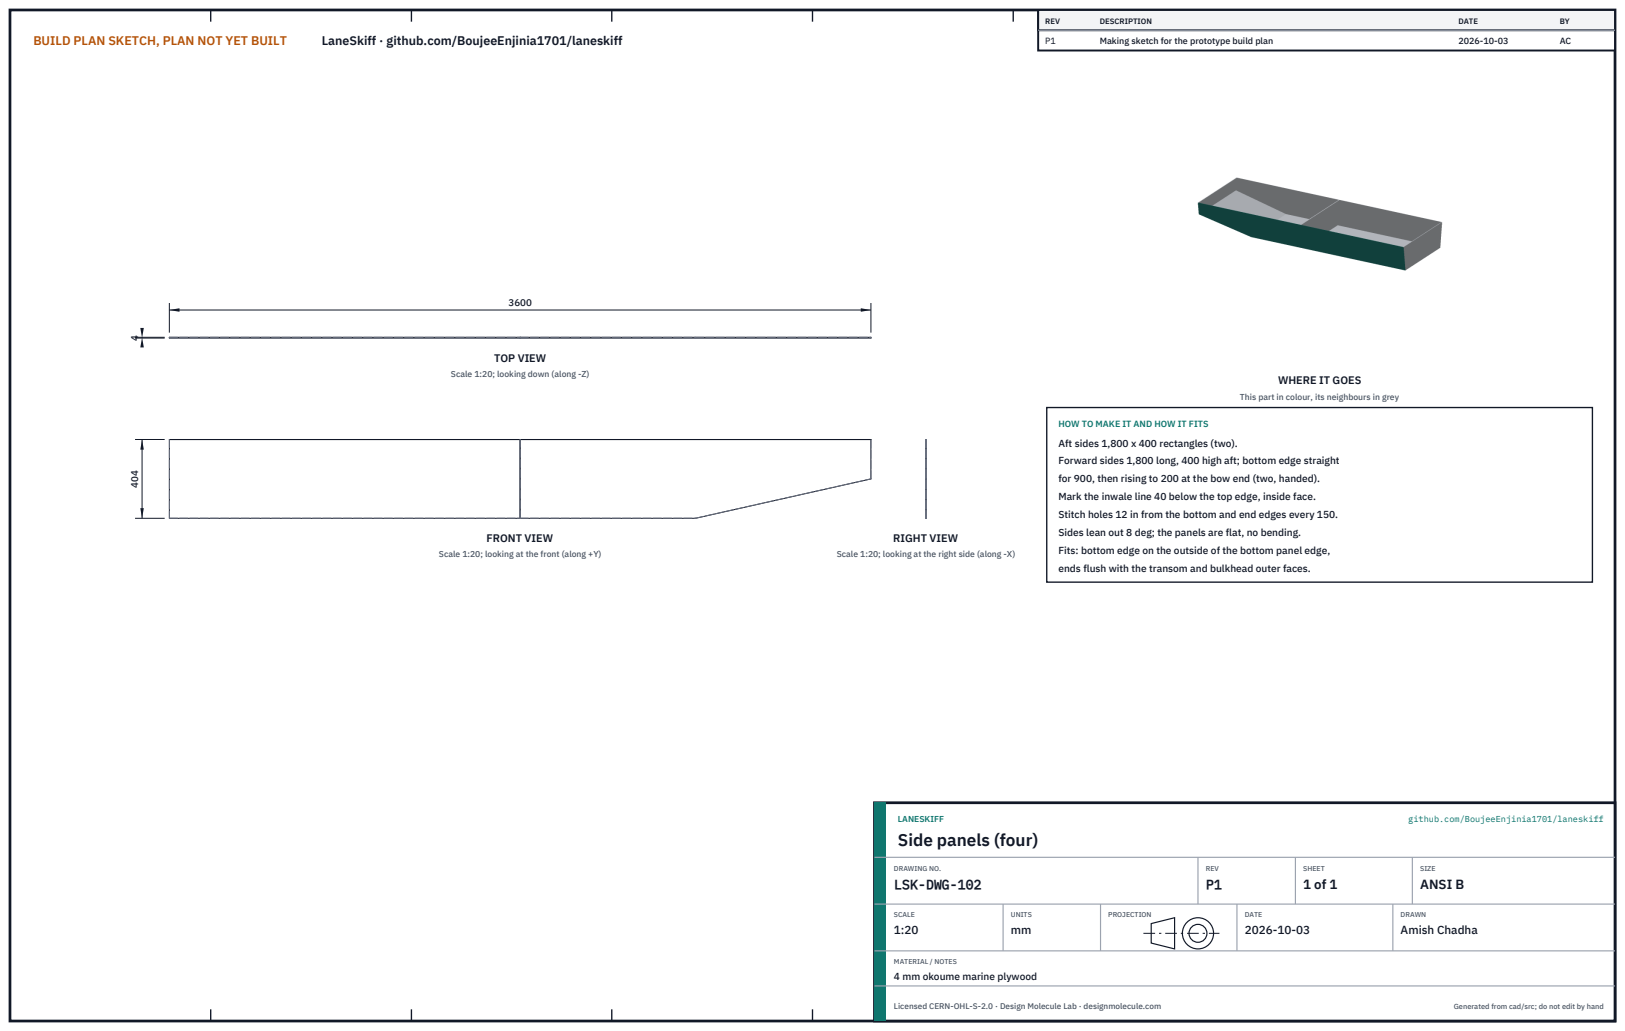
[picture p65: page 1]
BUILD PLAN SKETCH, PLAN NOT YET BUILT; LaneSkiff · github.com/BoujeeEnjinia1701/laneskiff; FRONT VIEW; TOP VIEW; RIGHT VIEW; REV; DESCRIPTION; DATE; Making sketch for the prototype build plan; LANESKIFF; github.com/BoujeeEnjinia1701/laneskiff; DRAWING NO. LSK-DWG-102; REV P1; SHEET 1 of 1; SIZE ANSI B; SCALE 1:20; UNITS mm; PROJECTION; DRAWN Amish Chadha; Licensed CERN-OHL-S-2.0 · Design Molecule Lab · designmolecule.com; Generated from cad/src; do not edit by hand

Scale 1:20; looking down (along -Z)

WHERE IT GOES

This part in colour, its neighbours in grey

HOW TO MAKE IT AND HOW IT FITS
Aft sides 1,800 x 400 rectangles (two).
Forward sides 1,800 long, 400 high aft; bottom edge straight
for 900, then rising to 200 at the bow end (two, handed).
Mark the inwale line 40 below the top edge, inside face.
Stitch holes 12 in from the bottom and end edges every 150.
Sides lean out 8 deg; the panels are flat, no bending.
Fits: bottom edge on the outside of the bottom panel edge,
ends flush with the transom and bulkhead outer faces.

Scale 1:20; looking at the front (along +Y)

Scale 1:20; looking at the right side (along -X)

Side panels (four)

MATERIAL / NOTES
4 mm okoume marine plywood

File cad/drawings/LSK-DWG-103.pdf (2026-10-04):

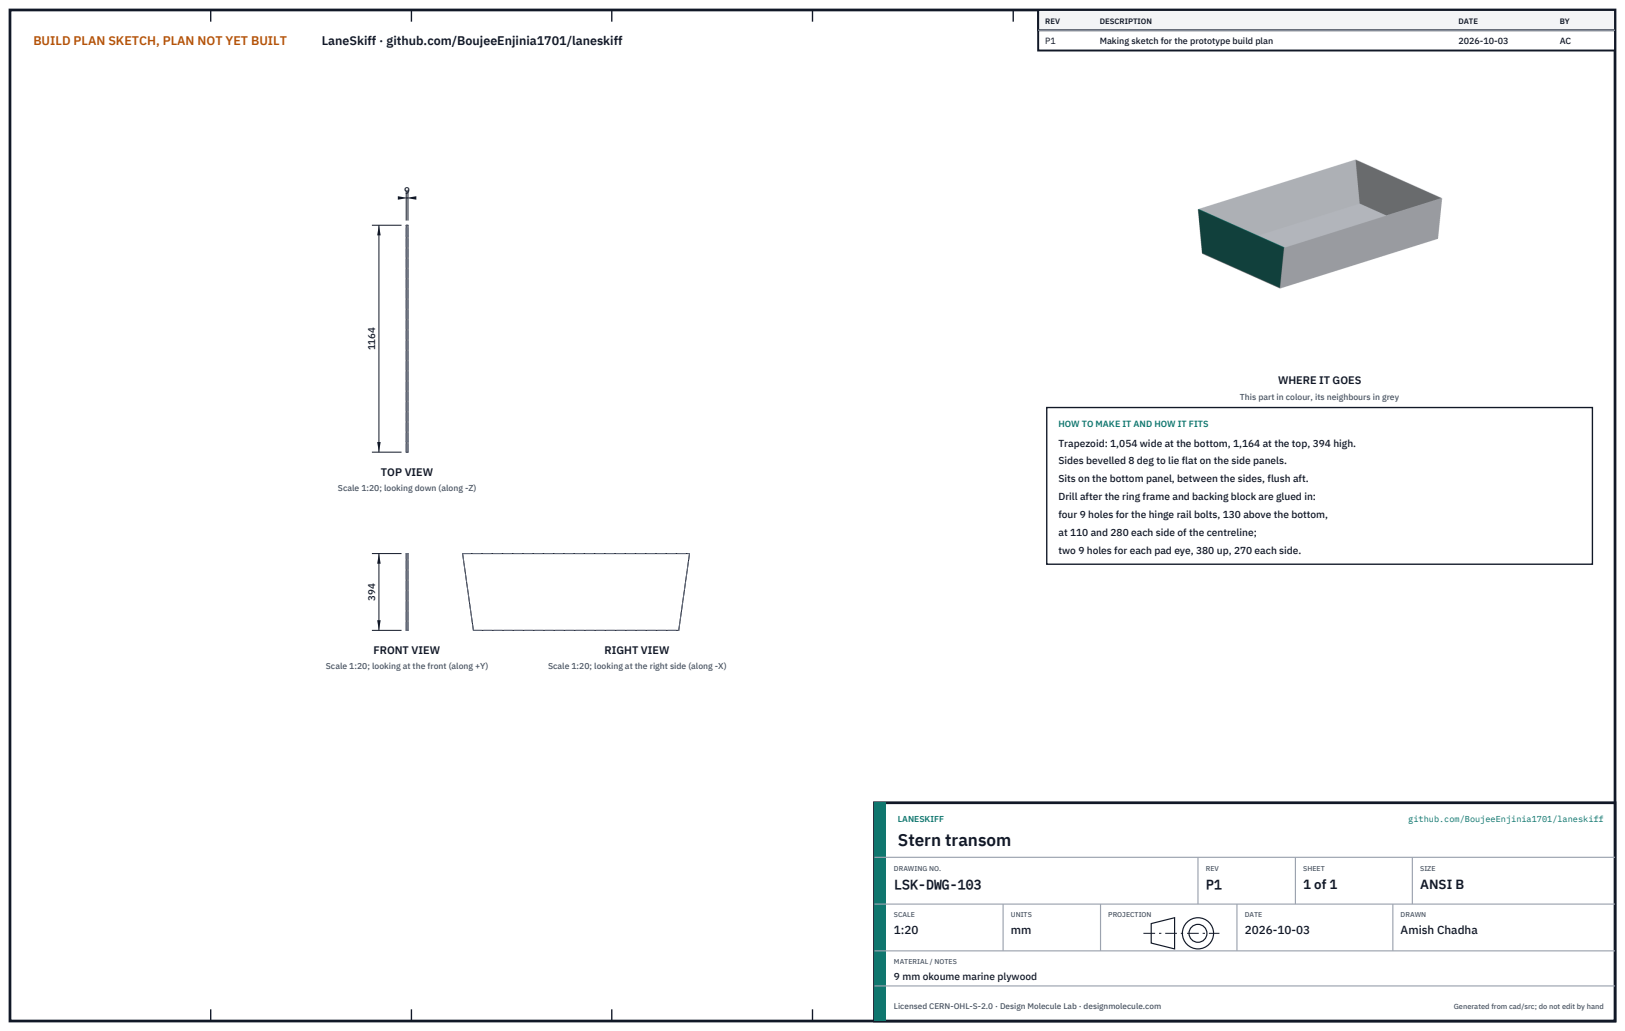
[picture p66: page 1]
BUILD PLAN SKETCH, PLAN NOT YET BUILT; LaneSkiff · github.com/BoujeeEnjinia1701/laneskiff; FRONT VIEW; TOP VIEW; RIGHT VIEW; REV; DESCRIPTION; DATE; Making sketch for the prototype build plan; LANESKIFF; github.com/BoujeeEnjinia1701/laneskiff; Stern transom; DRAWING NO. LSK-DWG-103; REV P1; SHEET 1 of 1; SIZE ANSI B; SCALE 1:20; UNITS mm; PROJECTION; DRAWN Amish Chadha; Licensed CERN-OHL-S-2.0 · Design Molecule Lab · designmolecule.com; Generated from cad/src; do not edit by hand

WHERE IT GOES

This part in colour, its neighbours in grey

HOW TO MAKE IT AND HOW IT FITS
Trapezoid: 1,054 wide at the bottom, 1,164 at the top, 394 high.
Sides bevelled 8 deg to lie flat on the side panels.
Sits on the bottom panel, between the sides, flush aft.
Drill after the ring frame and backing block are glued in:
four 9 holes for the hinge rail bolts, 130 above the bottom,
at 110 and 280 each side of the centreline;
two 9 holes for each pad eye, 380 up, 270 each side.

Scale 1:20; looking down (along -Z)

Scale 1:20; looking at the front (along +Y)

Scale 1:20; looking at the right side (along -X)

MATERIAL / NOTES
9 mm okoume marine plywood

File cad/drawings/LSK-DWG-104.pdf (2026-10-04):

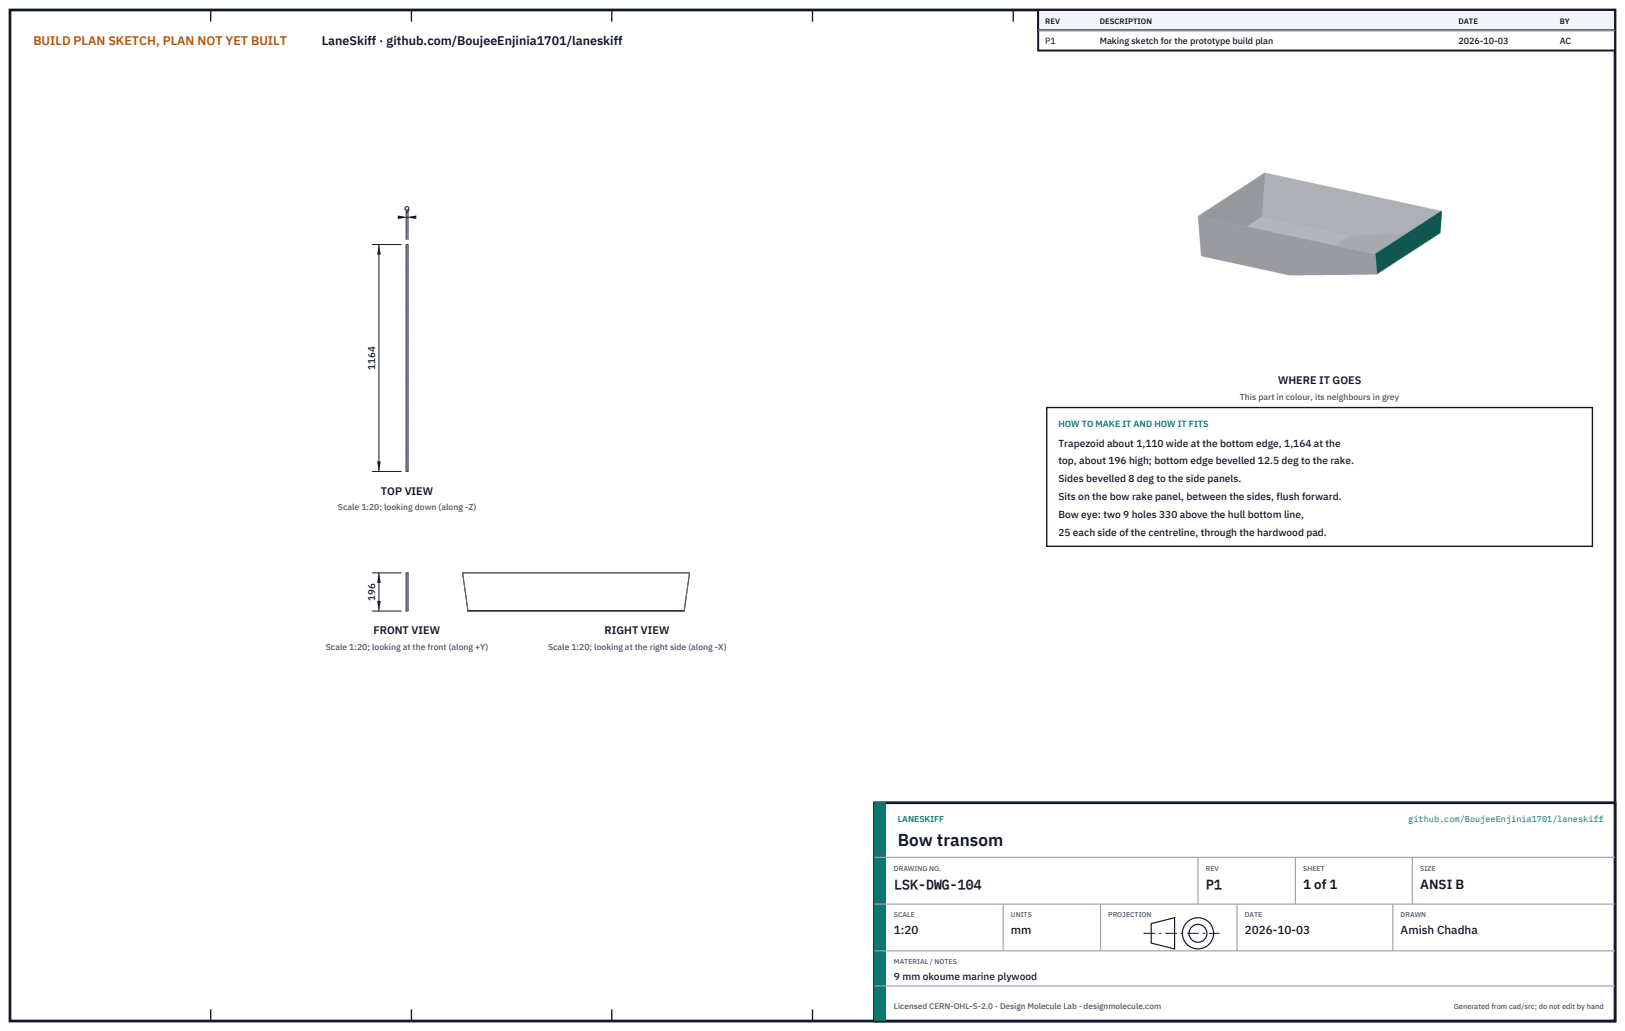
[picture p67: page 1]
BUILD PLAN SKETCH, PLAN NOT YET BUILT; LaneSkiff · github.com/BoujeeEnjinia1701/laneskiff; FRONT VIEW; TOP VIEW; RIGHT VIEW; REV; DESCRIPTION; DATE; Making sketch for the prototype build plan; LANESKIFF; github.com/BoujeeEnjinia1701/laneskiff; Bow transom; DRAWING NO. LSK-DWG-104; REV P1; SHEET 1 of 1; SIZE ANSI B; SCALE 1:20; UNITS mm; PROJECTION; DRAWN Amish Chadha; Licensed CERN-OHL-S-2.0 · Design Molecule Lab · designmolecule.com; Generated from cad/src; do not edit by hand

WHERE IT GOES

This part in colour, its neighbours in grey

HOW TO MAKE IT AND HOW IT FITS
Trapezoid about 1,110 wide at the bottom edge, 1,164 at the
top, about 196 high; bottom edge bevelled 12.5 deg to the rake.
Sides bevelled 8 deg to the side panels.
Sits on the bow rake panel, between the sides, flush forward.
Bow eye: two 9 holes 330 above the hull bottom line,
25 each side of the centreline, through the hardwood pad.

Scale 1:20; looking down (along -Z)

Scale 1:20; looking at the front (along +Y)

Scale 1:20; looking at the right side (along -X)

MATERIAL / NOTES
9 mm okoume marine plywood

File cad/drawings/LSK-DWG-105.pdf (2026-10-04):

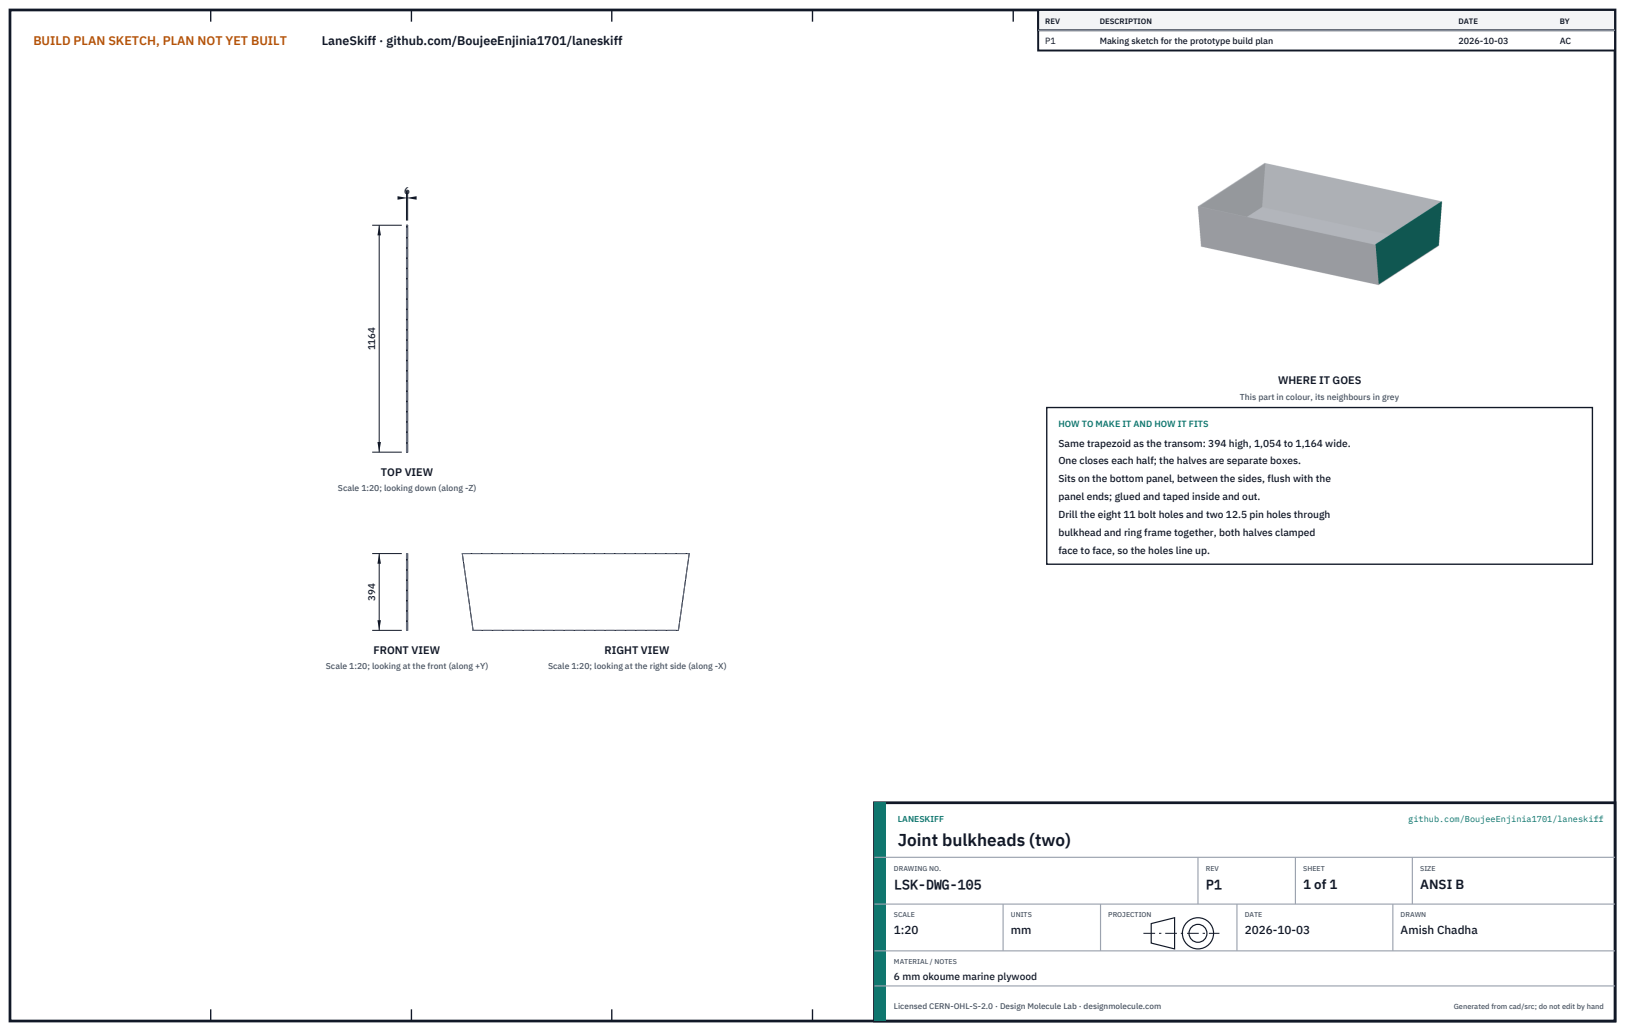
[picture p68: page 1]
BUILD PLAN SKETCH, PLAN NOT YET BUILT; LaneSkiff · github.com/BoujeeEnjinia1701/laneskiff; FRONT VIEW; TOP VIEW; RIGHT VIEW; REV; DESCRIPTION; DATE; Making sketch for the prototype build plan; LANESKIFF; github.com/BoujeeEnjinia1701/laneskiff; DRAWING NO. LSK-DWG-105; REV P1; SHEET 1 of 1; SIZE ANSI B; SCALE 1:20; UNITS mm; PROJECTION; DRAWN Amish Chadha; Licensed CERN-OHL-S-2.0 · Design Molecule Lab · designmolecule.com; Generated from cad/src; do not edit by hand

WHERE IT GOES

This part in colour, its neighbours in grey

HOW TO MAKE IT AND HOW IT FITS
Same trapezoid as the transom: 394 high, 1,054 to 1,164 wide.
One closes each half; the halves are separate boxes.
Sits on the bottom panel, between the sides, flush with the
panel ends; glued and taped inside and out.
Drill the eight 11 bolt holes and two 12.5 pin holes through
bulkhead and ring frame together, both halves clamped
face to face, so the holes line up.

Scale 1:20; looking down (along -Z)

Scale 1:20; looking at the front (along +Y)

Scale 1:20; looking at the right side (along -X)

Joint bulkheads (two)

MATERIAL / NOTES
6 mm okoume marine plywood

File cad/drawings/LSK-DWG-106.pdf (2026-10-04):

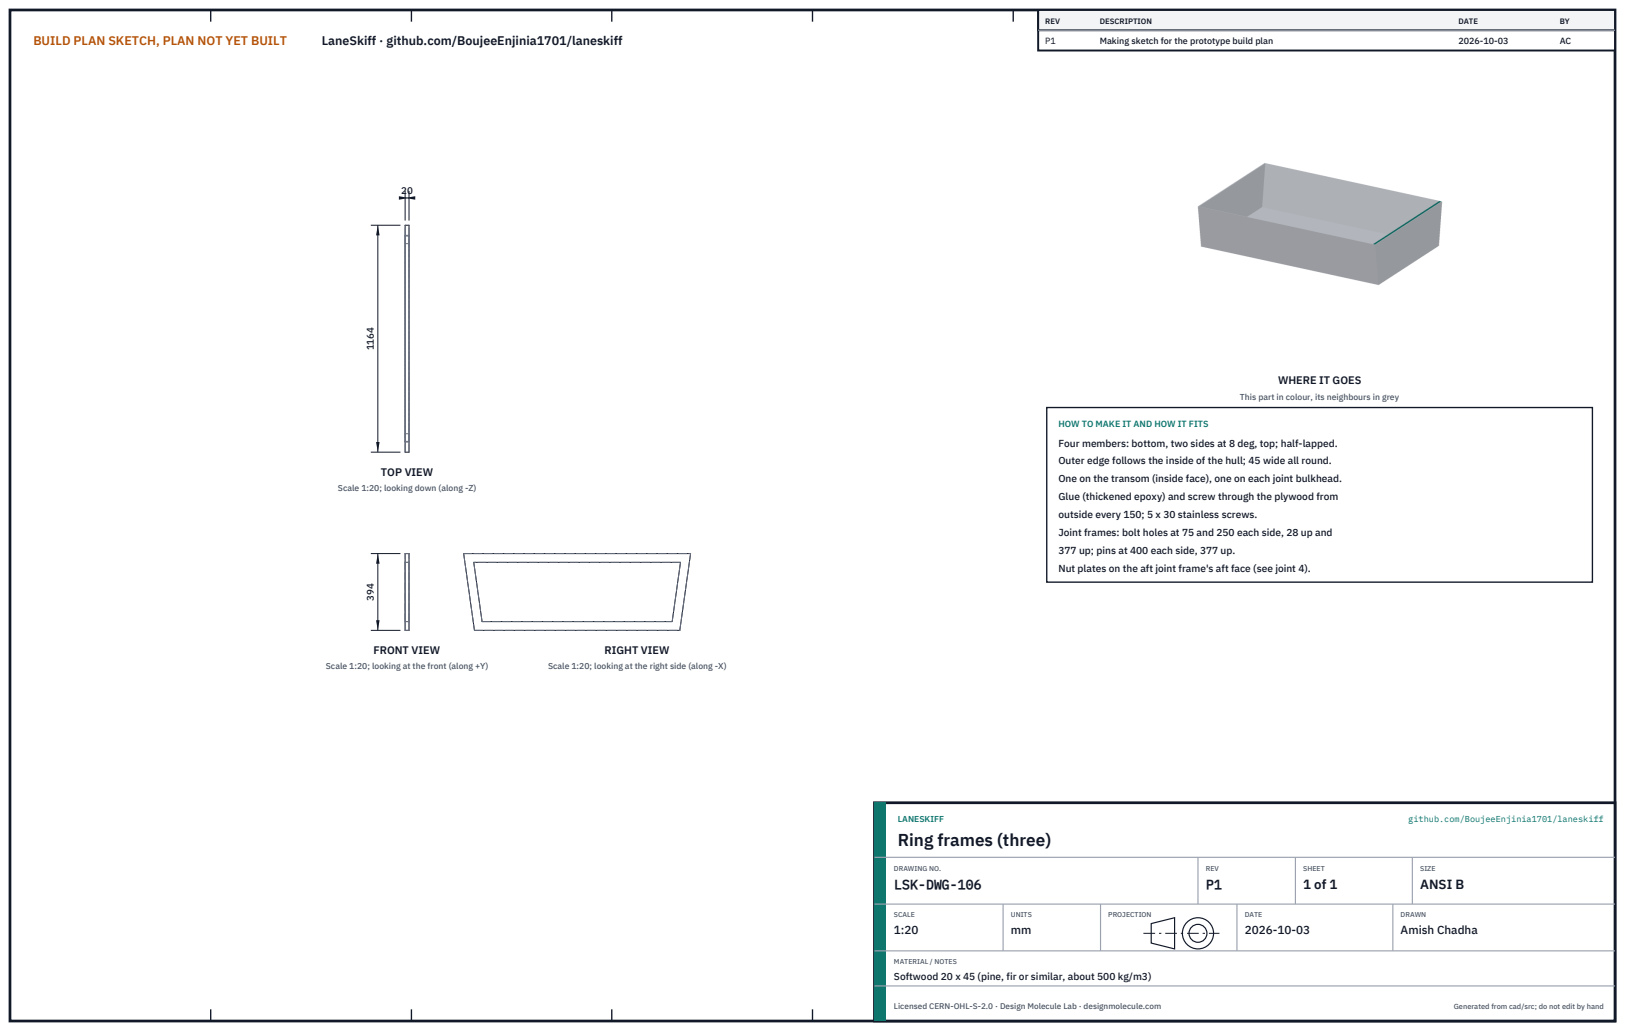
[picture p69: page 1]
BUILD PLAN SKETCH, PLAN NOT YET BUILT; LaneSkiff · github.com/BoujeeEnjinia1701/laneskiff; FRONT VIEW; TOP VIEW; RIGHT VIEW; REV; DESCRIPTION; DATE; Making sketch for the prototype build plan; LANESKIFF; github.com/BoujeeEnjinia1701/laneskiff; DRAWING NO. LSK-DWG-106; REV P1; SHEET 1 of 1; SIZE ANSI B; SCALE 1:20; UNITS mm; PROJECTION; DRAWN Amish Chadha; Licensed CERN-OHL-S-2.0 · Design Molecule Lab · designmolecule.com; Generated from cad/src; do not edit by hand

WHERE IT GOES

This part in colour, its neighbours in grey

HOW TO MAKE IT AND HOW IT FITS
Four members: bottom, two sides at 8 deg, top; half-lapped.
Outer edge follows the inside of the hull; 45 wide all round.
One on the transom (inside face), one on each joint bulkhead.
Glue (thickened epoxy) and screw through the plywood from
outside every 150; 5 x 30 stainless screws.
Joint frames: bolt holes at 75 and 250 each side, 28 up and
377 up; pins at 400 each side, 377 up.
Nut plates on the aft joint frame's aft face (see joint 4).

Scale 1:20; looking down (along -Z)

Scale 1:20; looking at the front (along +Y)

Scale 1:20; looking at the right side (along -X)

Ring frames (three)

MATERIAL / NOTES
Softwood 20 x 45 (pine, fir or similar, about 500 kg/m3)

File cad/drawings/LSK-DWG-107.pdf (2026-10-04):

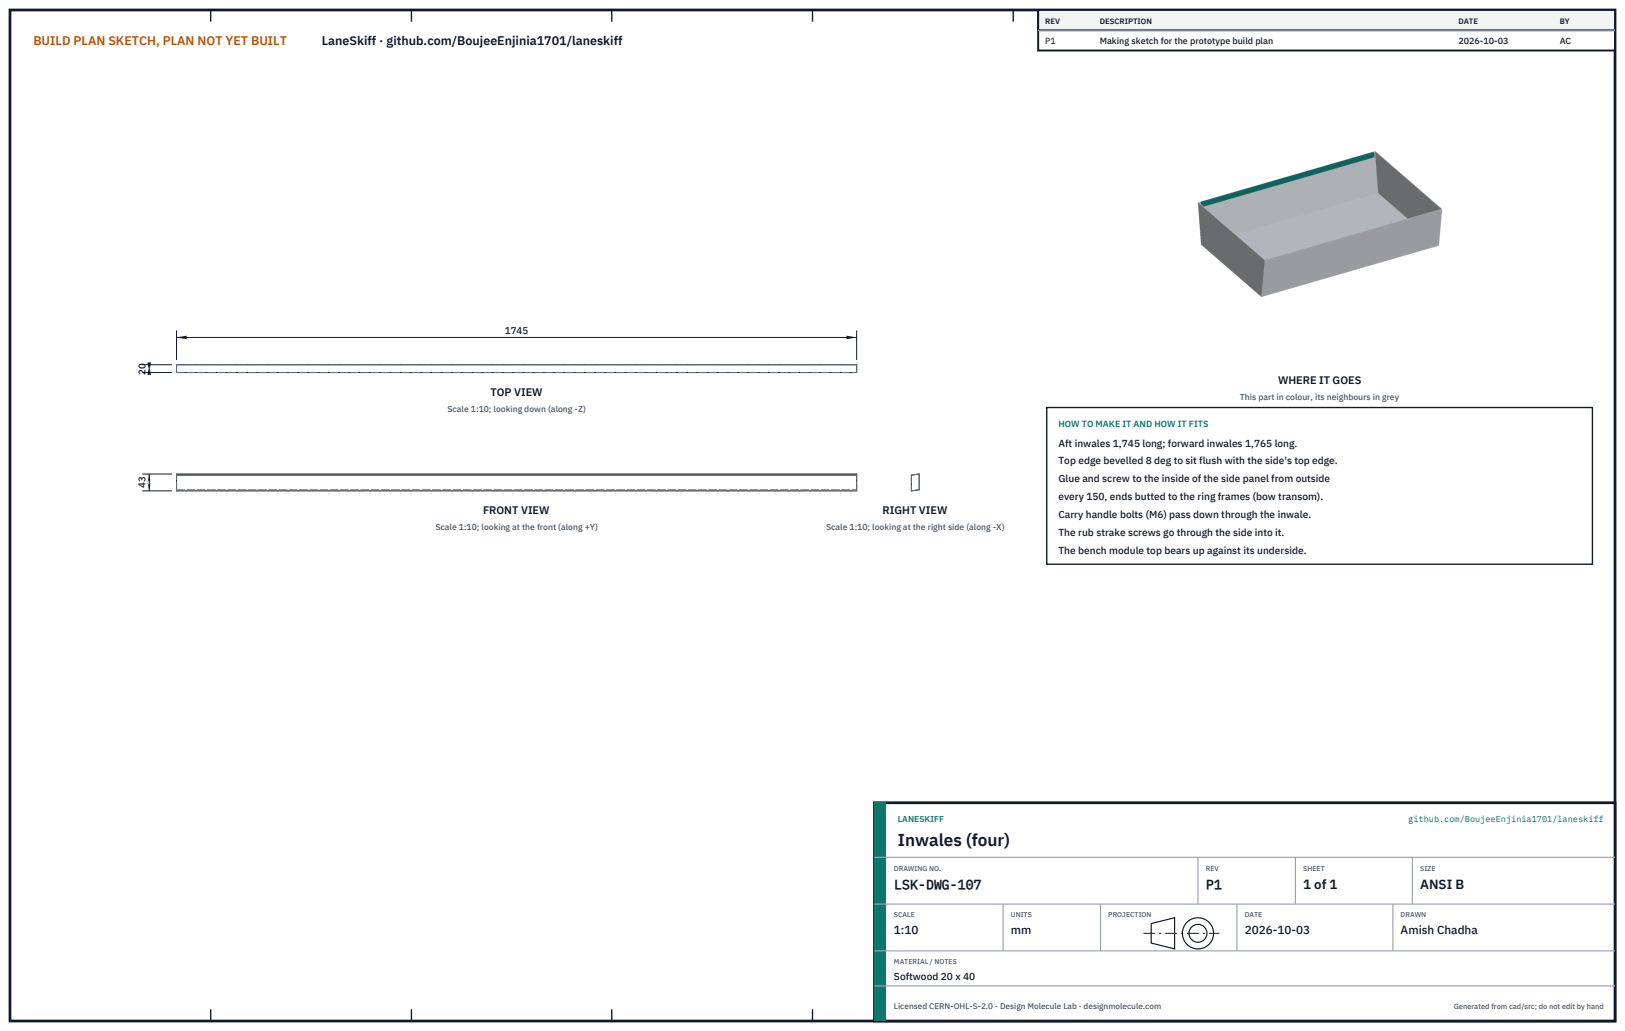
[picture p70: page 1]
BUILD PLAN SKETCH, PLAN NOT YET BUILT; LaneSkiff · github.com/BoujeeEnjinia1701/laneskiff; FRONT VIEW; TOP VIEW; RIGHT VIEW; REV; DESCRIPTION; DATE; Making sketch for the prototype build plan; LANESKIFF; github.com/BoujeeEnjinia1701/laneskiff; Inwales (four); DRAWING NO. LSK-DWG-107; REV P1; SHEET 1 of 1; SIZE ANSI B; SCALE 1:10; UNITS mm; PROJECTION; DRAWN Amish Chadha; MATERIAL / NOTES Softwood 20 x 40; Licensed CERN-OHL-S-2.0 · Design Molecule Lab · designmolecule.com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

WHERE IT GOES

This part in colour, its neighbours in grey

Scale 1:10; looking down (along -Z)

HOW TO MAKE IT AND HOW IT FITS
Aft inwales 1,745 long; forward inwales 1,765 long.
Top edge bevelled 8 deg to sit flush with the side's top edge.
Glue and screw to the inside of the side panel from outside
every 150, ends butted to the ring frames (bow transom).
Carry handle bolts (M6) pass down through the inwale.
The rub strake screws go through the side into it.
The bench module top bears up against its underside.

Scale 1:10; looking at the front (along +Y)

Scale 1:10; looking at the right side (along -X)

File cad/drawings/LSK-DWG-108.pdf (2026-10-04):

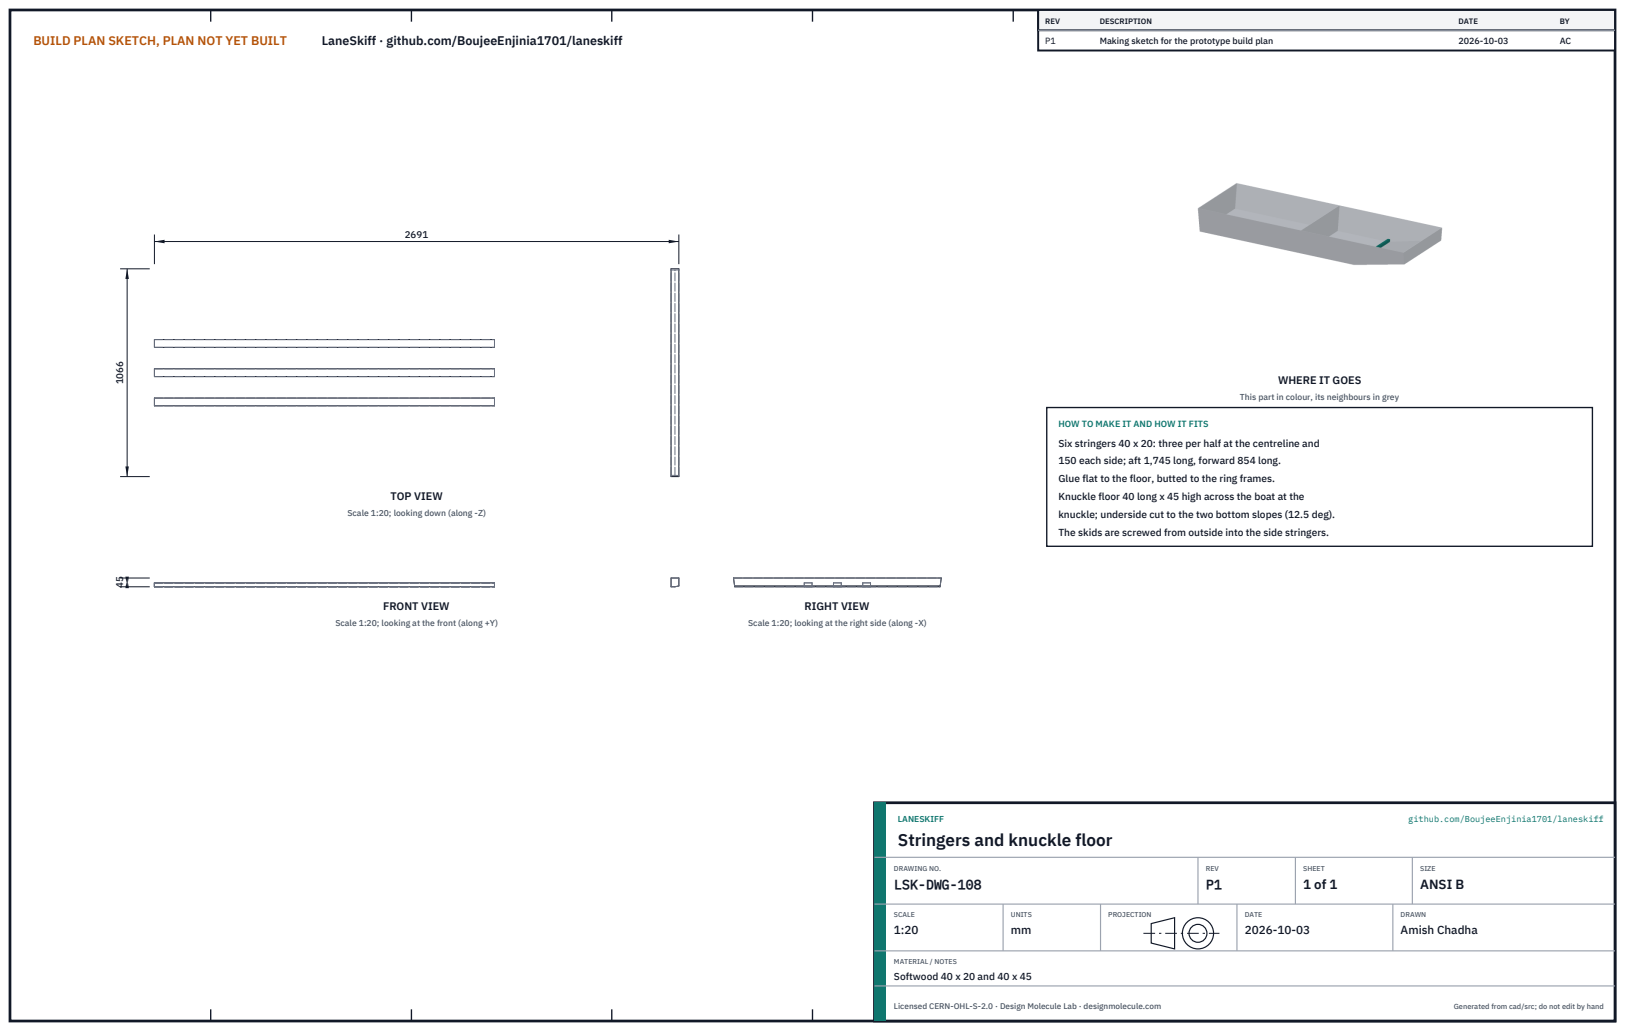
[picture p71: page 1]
BUILD PLAN SKETCH, PLAN NOT YET BUILT; LaneSkiff · github.com/BoujeeEnjinia1701/laneskiff; FRONT VIEW; TOP VIEW; RIGHT VIEW; REV; DESCRIPTION; DATE; Making sketch for the prototype build plan; LANESKIFF; github.com/BoujeeEnjinia1701/laneskiff; DRAWING NO. LSK-DWG-108; REV P1; SHEET 1 of 1; SIZE ANSI B; SCALE 1:20; UNITS mm; PROJECTION; DRAWN Amish Chadha; MATERIAL / NOTES Softwood 40 x 20 and 40 x 45; Licensed CERN-OHL-S-2.0 · Design Molecule Lab · designmolecule.com; Generated from cad/src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

WHERE IT GOES

This part in colour, its neighbours in grey

HOW TO MAKE IT AND HOW IT FITS
Six stringers 40 x 20: three per half at the centreline and
150 each side; aft 1,745 long, forward 854 long.
Glue flat to the floor, butted to the ring frames.
Knuckle floor 40 long x 45 high across the boat at the
knuckle; underside cut to the two bottom slopes (12.5 deg).
The skids are screwed from outside into the side stringers.

Scale 1:20; looking down (along -Z)

Scale 1:20; looking at the front (along +Y)

Scale 1:20; looking at the right side (along -X)

Stringers and knuckle floor

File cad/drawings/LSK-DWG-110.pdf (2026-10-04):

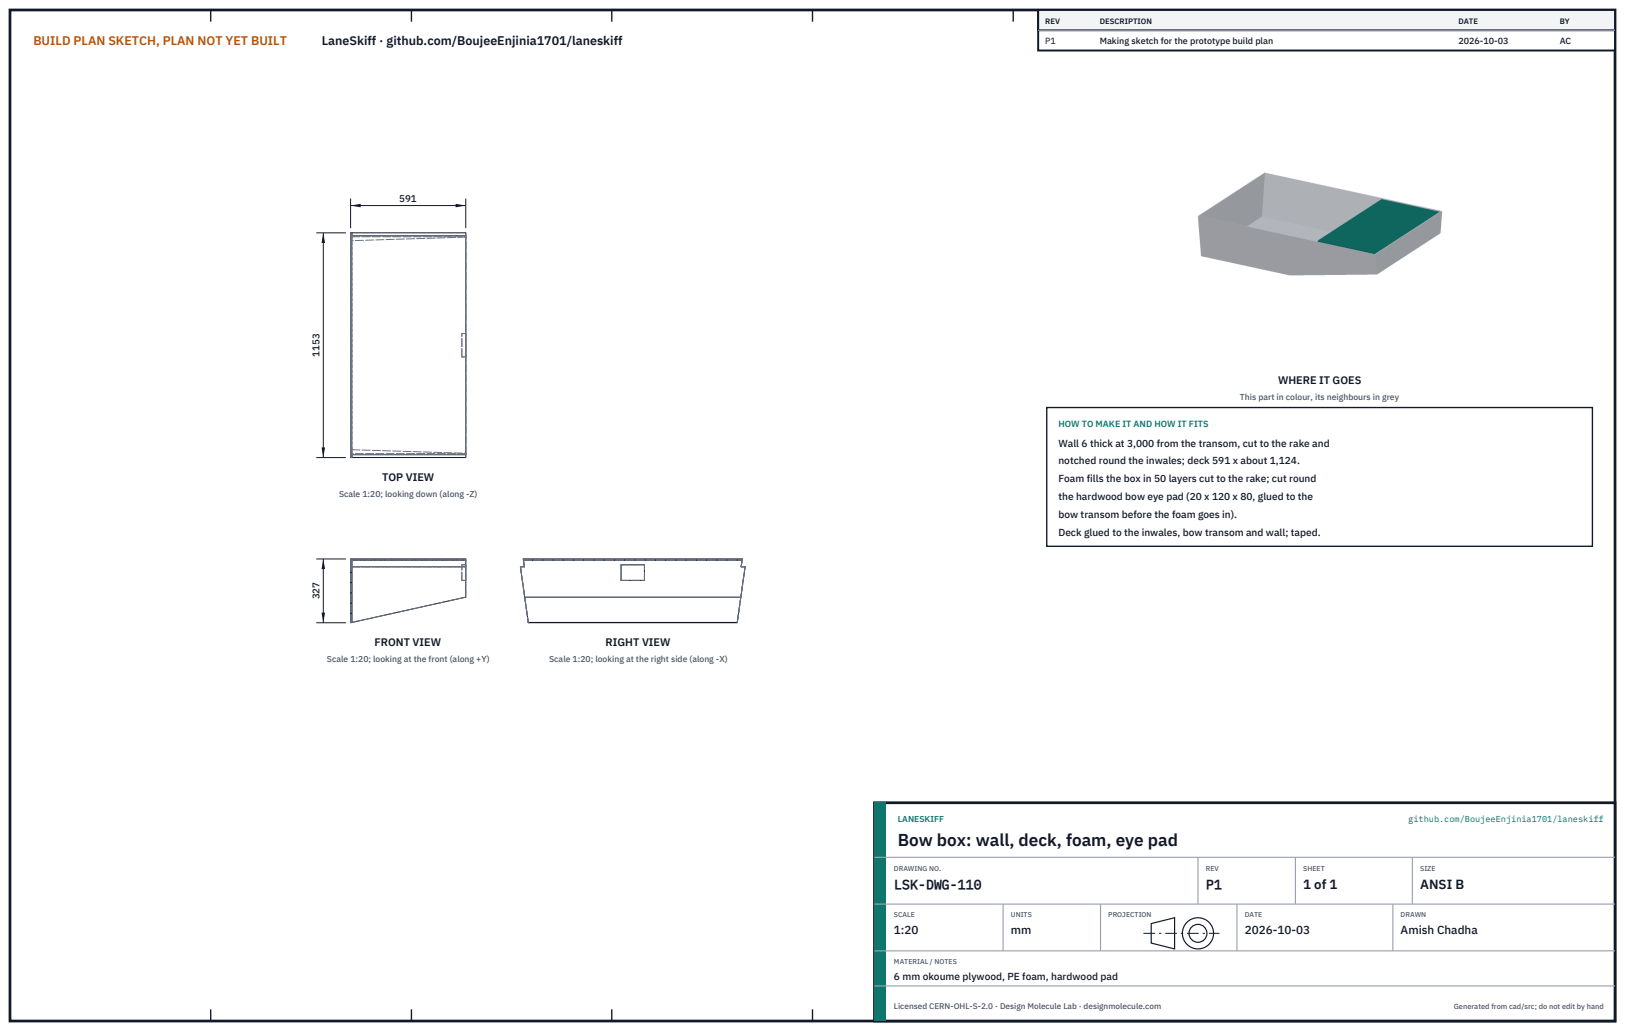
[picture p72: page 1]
BUILD PLAN SKETCH, PLAN NOT YET BUILT; LaneSkiff · github.com/BoujeeEnjinia1701/laneskiff; FRONT VIEW; TOP VIEW; RIGHT VIEW; REV; DESCRIPTION; DATE; Making sketch for the prototype build plan; LANESKIFF; github.com/BoujeeEnjinia1701/laneskiff; DRAWING NO. LSK-DWG-110; REV P1; SHEET 1 of 1; SIZE ANSI B; SCALE 1:20; UNITS mm; PROJECTION; DRAWN Amish Chadha; Licensed CERN-OHL-S-2.0 · Design Molecule Lab · designmolecule.com; Generated from cad/src; do not edit by hand

WHERE IT GOES

This part in colour, its neighbours in grey

HOW TO MAKE IT AND HOW IT FITS
Wall 6 thick at 3,000 from the transom, cut to the rake and
notched round the inwales; deck 591 x about 1,124.
Foam fills the box in 50 layers cut to the rake; cut round
the hardwood bow eye pad (20 x 120 x 80, glued to the
bow transom before the foam goes in).
Deck glued to the inwales, bow transom and wall; taped.

Scale 1:20; looking down (along -Z)

Scale 1:20; looking at the front (along +Y)

Scale 1:20; looking at the right side (along -X)

Bow box: wall, deck, foam, eye pad

MATERIAL / NOTES
6 mm okoume plywood, PE foam, hardwood pad

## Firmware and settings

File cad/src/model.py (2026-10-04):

"""LaneSkiff parametric model (build123d), TRL 3, constructable design (LSK-DDR-002, LSK-DDR-003).

Run from the repo root:  python cad/src/model.py [--check] [--export]
  --check   run the constructability checks (overlaps, contacts, bolt paths, step swing, beam)
  --export  write cad/step/*.step and cad/stl/*.stl

A flat-bottomed punt-form skiff in two rigid halves, plywood and epoxy build path (stitch and glue),
light timber specification (okoume plywood, 4 mm sides, softwood framing; LSK-DDR-003).
Each half is a closed box: its own end panel (transom or bow transom) and its own joint bulkhead,
so each half floats on its own and the joint between them needs no seal. The halves bolt together
through hardwood ring frames on the two joint bulkheads (eight M10 bolts into tee nuts).

Coordinates in mm. X along the boat from the outer face of the stern transom (x = 0) to the bow
(x = 3,600); Y across, port side positive; Z up from the outside of the bottom (z = 0). Hull sides
are flat panels flared outward by 8 deg. The bottom is 1,060 mm wide outside at the chine (LSK-DDR-003); it is flat to the knuckle at x = 2,700 and rakes
up to 200 mm at the bow.

Components (BOM line numbers in brackets, see bom/bom.csv):
  [1]  bottom panels, 6 mm plywood (aft, forward flat, bow rake)
  [2]  side panels, 4 mm plywood (4)
  [3]  stern transom, 9 mm plywood        [4]  bow transom, 9 mm plywood
  [5]  joint bulkheads, 6 mm plywood (2)  [6]  ring frames, softwood 20 x 45 (transom, two joint frames)
  [7]  inwales, softwood 20 x 40 (4)      [8]  bottom stringers, softwood 40 x 20 (6), knuckle floor
  [9]  bench modules: softwood bench rails, tarpaulin covers, webbing straps; bow box wall and deck, 6 mm plywood
  [10] buoyancy foam, closed-cell polyethylene (LevelHull layout: outboard benches and bow box)
  [29] stern quarter foam modules (2 x 15 L) in tarpaulin covers, strapped to the transom ring frame (LSK-DDR-003)
  [11] joint bolts M10 x 80 into welded nut plates (8), alignment pins (2)
  [12] rub strakes, HDPE 12 x 30 (4)      [13] bottom skids, HDPE 40 x 8 (4)
  [14] stern step: hinge rail, transom backing block, M8 bolts, float (rim, decks, foam), strap hinges
  [15] step stop straps and pad eyes      [16] kick rung on straps
  [17] transom grab handles (2)           [18] carry handles (8)
  [19] push pole, two 1.5 m sections      [20] paddles (2)
  [21] bow eye, backing pad and bow line
CONCEPT, NOT FOR FABRICATION.
"""
import math
import sys
from pathlib import Path

from build123d import (Axis, Box, Compound, Cylinder, Face, Pos, Rot, Torus, Vector, Wire,
                       extrude, export_step, export_stl)

ROOT = Path(__file__).resolve().parents[2]

PARAMS = {
    "L": 3600.0,            # overall length of the hull (bow transom outer face)
    "x_joint": 1800.0,      # joint plane between the halves (faces of the two bulkheads)
    "knuckle": 2700.0,      # bottom knuckle, start of the bow rake
    "rise": 200.0,          # bottom height at the bow
    "D": 400.0,             # side height (sheer), constant
    "half_bot": 530.0,      # outer half width of the bottom at the chine (500 widened 30 a side, LSK-DDR-003)
    "flare_deg": 8.0,       # side flare from vertical
    "t_bot": 6.0, "t_side": 4.0, "t_transom": 9.0, "t_bow": 9.0, "t_bh": 6.0,
    "cover_t": 2.0, "t_box": 6.0,
    "bench_rail": (40.0, 20.0),   # hardwood rail on the floor along the inboard foot of each bench module
    "strap": (50.0, 2.5), "straps_aft": 3, "straps_fwd": 2,
    "frame": (20.0, 45.0),      # ring frames: thickness along the boat, member width
    "inwale": (20.0, 40.0),     # thickness square to the side, height
    "stringer": (40.0, 20.0),   # width, height
    "stringer_y": 150.0,
    "floor": (40.0, 45.0),      # knuckle floor: length along the boat, height
    "bench_y": 330.0,           # inboard face of the bench modules from the centreline
    "bench_top": 360.0,         # bench top, level with the underside of the inwale
    "bench_fwd_end": 2680.0,    # forward bench boxes stop at the knuckle floor
    "bow_box_x": 3000.0,        # aft face of the bow box wall
    # stern quarter foam modules (LSK-DDR-003): foam core length along the boat, width, height; inboard face y
    "quarter": (250.0, 190.0, 316.0), "quarter_y": 125.0, "quarter_x": 40.0,
    "strake": (12.0, 30.0),     # HDPE rub strake: thickness, height
    "skid": (40.0, 8.0),        # HDPE skid: width, thickness
    "joint_bolts": [(-250.0, "b"), (-75.0, "b"), (75.0, "b"), (250.0, "b"),
                    (-250.0, "t"), (-100.0, "t"), (100.0, "t"), (250.0, "t")],
    "pins_y": (-400.0, 400.0),
    # stern step (hinged float with a hanging kick rung)
    "rail": (40.0, 60.0, 640.0, 100.0),    # thickness aft of the transom, height, length, bottom edge z
    "gap": 40.0,                           # rail to float gap
    "float": (450.0, 600.0, 90.0, 70.0),   # length (aft), width, depth, bottom z when deployed
    "float_rim": 20.0, "float_top": 9.0, "float_bot": 6.0,
    "hinge_y": (-200.0, 200.0),
    "stop_deg": 20.0,                      # step swings at most this far below level (stop straps)
    "rung_drop": 270.0,                    # rung centre below the float bottom
    "rung": (16.0, 560.0),                 # radius, length
    "rail_bolts_y": (-280.0, -110.0, 110.0, 280.0),
    "grab_y": (-250.0, 250.0), "grab": (250.0, 120.0),
    "carry_x": [300.0, 1550.0, 2050.0, 3300.0], "carry": (200.0, 50.0),
    "pole": (19.0, 1500.0), "paddle": (1400.0, 160.0, 12.0, 450.0),
}

AFT, FWD = "aft", "fwd"


# ---------------------------------------------------------------- geometry helpers
def tf(p=PARAMS):
    a = math.radians(p["flare_deg"])
    return math.tan(a), math.cos(a)


def half(z, d=0.0, p=PARAMS):
    """Half width at height z of the plane offset d (square to the side) inward from the outside."""
    t, c = tf(p)
    return p["half_bot"] + z * t - d / c


def zb(x, p=PARAMS):
    """Height of the outside of the bottom at x."""
    k, L = p["knuckle"], p["L"]
    return 0.0 if x <= k else p["rise"] * (x - k) / (L - k)


def ztop_bottom(x, p=PARAMS):
    return zb(x, p) + p["t_bot"]


def trap(d, z0, z1, p=PARAMS):
    return [(-half(z0, d, p), z0), (half(z0, d, p), z0), (half(z1, d, p), z1), (-half(z1, d, p), z1)]


def yz_x(poly, x0, x1):
    """Prism of a (y, z) polygon from x0 to x1."""
    w = Wire.make_polygon([Vector(x0, y, z) for y, z in poly], close=True)
    return extrude(Face(w), amount=x1 - x0, dir=(1, 0, 0))


def xz_y(poly, y0=-900.0, y1=900.0):
    """Prism of an (x, z) polygon from y0 to y1."""
    w = Wire.make_polygon([Vector(x, y0, z) for x, z in poly], close=True)
    return extrude(Face(w), amount=y1 - y0, dir=(0, 1, 0))


def rect_xz(x0, x1, z0, z1):
    return [(x0, z0), (x1, z0), (x1, z1), (x0, z1)]


def inner(x0, x1, p=PARAMS, z0=-20.0, z1=None):
    """Space between the inner faces of the side panels."""
    return yz_x(trap(p["t_side"], z0, (z1 or p["D"] + 20), p), x0, x1)


def box(x0, x1, y0, y1, z0, z1):
    return Pos((x0 + x1) / 2, (y0 + y1) / 2, (z0 + z1) / 2) * Box(x1 - x0, y1 - y0, z1 - z0)


def flat(shapes):
    """One compound of every solid in shapes (nested compounds report no volume)."""
    sol = []
    for s in shapes:
        sol += list(s.solids()) if hasattr(s, "solids") else [s]
    return Compound(sol)


def rod(a, b, r):
    a, b = Vector(*a), Vector(*b)
    v = b - a
    L = v.length
    c = Cylinder(r, L)
    z = Vector(0, 0, 1)
    ax = z.cross(v)
    if ax.length < 1e-9:
        rot = c if v.Z > 0 else Rot(180, 0, 0) * c
    else:
        ang = math.degrees(math.acos(max(-1, min(1, z.dot(v) / L))))
        rot = c.rotate(Axis((0, 0, 0), (ax.X, ax.Y, ax.Z)), ang)
    return Pos(*(a + v * 0.5)) * rot


def port_stbd_split(shape):
    big = 2000.0
    return shape & box(-500, 4200, 0, big, -500, 900), shape & box(-500, 4200, -big, 0, -500, 900)


def mirror_y(shape):
    from build123d import Plane, mirror
    return mirror(shape, about=Plane.XZ)


# ---------------------------------------------------------------- derived x stations
def stations(p=PARAMS):
    fx, fw = p["frame"]
    xj = p["x_joint"]
    tt, tbh, tbw = p["t_transom"], p["t_bh"], p["t_bow"]
    return {
        "transom": (0.0, tt), "tframe": (tt, tt + fx),
        "bh_aft": (xj - tbh, xj), "fr_aft": (xj - tbh - fx, xj - tbh),
        "bh_fwd": (xj, xj + tbh), "fr_fwd": (xj + tbh, xj + tbh + fx),
        "bow": (p["L"] - tbw, p["L"]),
        "floor": (p["knuckle"] - p["floor"][0] / 2, p["knuckle"] + p["floor"][0] / 2),
        "aft_in": (tt + fx, xj - tbh - fx), "fwd_in": (xj + tbh + fx, p["L"] - tbw),
    }


# ---------------------------------------------------------------- hull halves
def hull_parts(p=PARAMS):
    """Every made hull piece of both halves: dict name -> (half, BOM line, shape)."""
    S = stations(p)
    D, tb, ts = p["D"], p["t_bot"], p["t_side"]
    L, K, xj = p["L"], p["knuckle"], p["x_joint"]
    fx, fw = p["frame"]
    out = {}

    def add(name, half_, bom, shape):
        out[name] = (half_, bom, shape)

    # [1] bottom panels, between the side panels
    add("bottom aft", AFT, 1, xz_y(rect_xz(0, xj, 0, tb)) & inner(0, xj, p))
    add("bottom forward flat", FWD, 1, xz_y(rect_xz(xj, K, 0, tb)) & inner(xj, K, p))
    add("bottom bow rake", FWD, 1, xz_y([(K, 0), (L, p["rise"]), (L, p["rise"] + tb), (K, tb)]) & inner(K, L, p))
    # [2] side panels, full length of each half, bottom edge to the sheer
    wall = yz_x(trap(0, 0, D, p), -10, L + 10) - yz_x(trap(ts, -10, D + 10, p), -20, L + 20)
    prof_a = xz_y(rect_xz(0, xj, 0, D))
    prof_f = xz_y([(xj, 0), (K, 0), (L, p["rise"]), (L, D), (xj, D)])
    for half_, prof, tag in ((AFT, prof_a, "aft"), (FWD, prof_f, "forward")):
        sp, ss = port_stbd_split(wall & prof)
        add(f"side {tag} port", half_, 2, sp)
        add(f"side {tag} starboard", half_, 2, ss)
    # [3] stern transom and [4] bow transom, on the bottom between the sides
    x0, x1 = S["transom"]
    add("stern transom", AFT, 3, xz_y(rect_xz(x0, x1, tb, D)) & inner(x0, x1, p))
    x0, x1 = S["bow"]
    add("bow transom", FWD, 4, xz_y([(x0, ztop_bottom(x0, p)), (x1, ztop_bottom(x1, p)), (x1, D), (x0, D)])
        & inner(x0, x1, p))
    # [5] joint bulkheads
    for key, half_, tag in (("bh_aft", AFT, "aft"), ("bh_fwd", FWD, "forward")):
        x0, x1 = S[key]
        add(f"joint bulkhead {tag}", half_, 5, xz_y(rect_xz(x0, x1, tb, D)) & inner(x0, x1, p))
    # [6] ring frames (hardwood 20 x 45 members round the inside of the transom and both bulkheads)
    for key, half_, tag in (("tframe", AFT, "transom"), ("fr_aft", AFT, "joint aft"), ("fr_fwd", FWD, "joint forward")):
        x0, x1 = S[key]
        ring = (xz_y(rect_xz(x0, x1, tb, D)) & inner(x0, x1, p)) - yz_x(trap(ts + fw, tb + fw, D - fw, p), x0 - 1, x1 + 1)
        add(f"ring frame {tag}", half_, 6, ring)
    # [7] inwales, inside the top of each side panel, frame to frame (to the bow transom forward)
    iw, ih = p["inwale"]
    for half_, (x0, x1), tag in ((AFT, S["aft_in"], "aft"), (FWD, S["fwd_in"], "forward")):
        band = yz_x(trap(ts, D - ih, D, p), x0, x1) - yz_x(trap(ts + iw, D - ih - 1, D + 1, p), x0 - 1, x1 + 1)
        ip, is_ = port_stbd_split(band)
        add(f"inwale {tag} port", half_, 7, ip)
        add(f"inwale {tag} starboard", half_, 7, is_)
    # [8] bottom stringers (two per half) and the knuckle floor
    sw, sh = p["stringer"]
    for half_, (x0, x1), tag in ((AFT, S["aft_in"], "aft"), (FWD, (S["fwd_in"][0], S["floor"][0]), "forward")):
        for sy, side in ((p["stringer_y"], "port"), (0.0, "centre"), (-p["stringer_y"], "starboard")):
            add(f"stringer {tag} {side}", half_, 8, box(x0, x1, sy - sw / 2, sy + sw / 2, tb, tb + sh))
    f0, f1 = S["floor"]
    fh = p["floor"][1]
    add("knuckle floor", FWD, 8, xz_y([(f0, tb), (K, tb), (f1, ztop_bottom(f1, p)), (f1, tb + fh), (f0, tb + fh)])
        & inner(f0, f1, p))
    # [9] bench modules (LevelHull layout): foam cores in sewn tarpaulin covers, outboard on both sides of both
    # halves, held under the inwale by the inwale itself and by webbing straps to a hardwood bench rail on the floor
    by, bt, ct = p["bench_y"], p["bench_top"], p["cover_t"]
    rw, rh = p["bench_rail"]
    sw_, st_ = p["strap"]
    iw = p["inwale"][0]
    for half_, (x0, x1), tag, ns in ((AFT, S["aft_in"], "aft", p["straps_aft"]),
                                     (FWD, (S["fwd_in"][0], p["bench_fwd_end"]), "forward", p["straps_fwd"])):
        env = yz_x([(by, tb), (half(tb, ts, p), tb), (half(bt, ts, p), bt), (by, bt)], x0, x1)
        core = yz_x([(by + ct, tb + ct), (half(tb + ct, ts + ct, p), tb + ct), (half(bt - ct, ts + ct, p), bt - ct),
                     (by + ct, bt - ct)], x0 + ct, x1 - ct)
        rail = box(x0, x1, by - rw, by, tb, tb + rh)
        straps = []
        for k in range(ns):
            xs = x0 + (x1 - x0) * (k + 1) / (ns + 1)
            a, b = xs - sw_ / 2, xs + sw_ / 2
            yi = half(bt + st_, ts + iw, p)
            top_band = yz_x([(by - st_, bt), (half(bt, ts + iw, p), bt), (yi, bt + st_), (by - st_, bt + st_)], a, b)
            straps += [top_band, box(a, b, by - st_, by, tb + rh, bt), box(a, b, by - rw, by - st_, tb + rh, tb + rh + st_)]
        strap = straps[0]
        for q in straps[1:]:
            strap = strap.fuse(q)
        for side, f in (("port", lambda s_: s_), ("starboard", mirror_y)):
            add(f"bench rail {tag} {side}", half_, 9, f(rail))
            add(f"bench cover {tag} {side}", half_, 9, f(env - core))
            add(f"bench foam {tag} {side}", half_, 10, f(core))
            add(f"bench straps {tag} {side}", half_, 9, f(strap))
    # bow box: aft wall and deck (6 mm plywood) closing the foam block under the bow deck
    tbx = p["t_box"]
    bx = p["bow_box_x"]
    xb1 = S["bow"][0]
    inw = Compound([v[2] for k, v in out.items() if k.startswith("inwale forward")])
    wall_b = (xz_y([(bx, ztop_bottom(bx, p)), (bx + tbx, ztop_bottom(bx + tbx, p)), (bx + tbx, D - tbx), (bx, D - tbx)])
              & inner(bx, bx + tbx, p)) - inw
    deck = (xz_y(rect_xz(bx, xb1, D - tbx, D)) & inner(bx, xb1, p)) - inw
    add("bow box wall", FWD, 9, wall_b)
    add("bow deck", FWD, 9, deck)
    # bow eye backing pad (hardwood) inside the bow transom, cut out of the bow foam
    pad = box(xb1 - 20, xb1, -60, 60, 290, 370)
    add("bow eye pad", FWD, 21, pad)
    bow_foam = (xz_y([(bx + tbx, ztop_bottom(bx + tbx, p)), (xb1, ztop_bottom(xb1, p)), (xb1, D - tbx), (bx + tbx, D - tbx)])
                & inner(bx + tbx, xb1, p)) - inw - pad
    add("bow foam", FWD, 10, bow_foam)
    # [29] stern quarter foam modules (LSK-DDR-003): a 15 L foam core in a tarpaulin cover either side of the step
    # opening, sitting on the side stringer and the bench rail, clear of the transom's rail bolt nuts, held by a
    # webbing strap screwed to the inside face of the transom ring frame's top member and to the side stringer
    ql, qw, qh = p["quarter"]
    qy = p["quarter_y"]
    sw_, st_ = p["strap"]
    xq0 = p["quarter_x"]                       # aft face, clear of the rail bolt nuts on the ring frame
    zq0 = tb + p["stringer"][1]                # on the stringer and bench rail tops
    qenv = box(xq0, xq0 + ql + 2 * ct, qy, qy + qw + 2 * ct, zq0, zq0 + qh + 2 * ct)
    qcore = box(xq0 + ct, xq0 + ql + ct, qy + ct, qy + qw + ct, zq0 + ct, zq0 + qh + ct)
    xq1, zq1 = xq0 + ql + 2 * ct, zq0 + qh + 2 * ct
    a_, b_ = qy, qy + sw_                     # strap over the inboard edge, in line with the side stringer
    xf = S["tframe"][1]
    qstrap = box(xf, xf + st_, a_, b_, zq1, D - 10)                       # aft leg up the ring frame top member
    qstrap = qstrap.fuse(box(xf, xq1 + st_, a_, b_, zq1, zq1 + st_))       # over the top
    qstrap = qstrap.fuse(box(xq1, xq1 + st_, a_, b_, zq0, zq1))            # down the forward face
    qstrap = qstrap.fuse(box(xq1, xq1 + 40, a_, b_, zq0, zq0 + st_))       # foot tab screwed to the stringer
    for side, f in (("port", lambda s_: s_), ("starboard", mirror_y)):
        add(f"quarter cover {side}", AFT, 29, f(qenv - qcore))
        add(f"quarter foam {side}", AFT, 29, f(qcore))
        add(f"quarter strap {side}", AFT, 29, f(qstrap))
    # [12] rub strakes outside the sheer, [13] skids under the bottom
    so, sh2 = p["strake"]
    st = yz_x(trap(-so, D - sh2, D, p), -1, L + 1) - yz_x(trap(0, D - sh2 - 1, D + 1, p), -2, L + 2)
    for half_, (x0, x1), tag in ((AFT, (0, xj), "aft"), (FWD, (xj, L), "forward")):
        sp, ss = port_stbd_split(st & box(x0, x1, -900, 900, 0, 600))
        add(f"rub strake {tag} port", half_, 12, sp)
        add(f"rub strake {tag} starboard", half_, 12, ss)
    kw, kt = p["skid"]
    for sy, side in ((p["stringer_y"], "port"), (-p["stringer_y"], "starboard")):
        y0, y1 = sy - kw / 2, sy + kw / 2
        add(f"skid aft {side}", AFT, 13, xz_y(rect_xz(0, xj, -kt, 0), y0, y1))
        add(f"skid forward {side}", FWD, 13,
            xz_y([(xj, -kt), (K, -kt), (L, p["rise"] - kt), (L, p["rise"]), (K, 0), (xj, 0)], y0, y1))
    return out


# ---------------------------------------------------------------- joint hardware
def joint_hardware(p=PARAMS):
    """Eight M10 x 80 hex bolts (heads forward) into captive nut plates on the aft ring frame, two alignment pins.
    A nut plate is a 40 x 40 x 3 mm steel plate with an M10 nut welded on, screwed to the frame's aft face, so the
    halves are joined with one spanner from the forward side."""
    S = stations(p)
    fw = p["frame"][1]
    a0 = S["fr_aft"][0]
    f1 = S["fr_fwd"][1]
    zbot = p["t_bot"] + fw / 2
    ztop = p["D"] - fw / 2
    bolts = []
    for y, row in p["joint_bolts"]:
        z = zbot if row == "b" else ztop
        shank = rod((a0 - 11, y, z), (f1 + 7, y, z), 5.0)
        head = Pos(f1 + 2 + 6.4 / 2 + 1, y, z) * Rot(0, 90, 0) * Cylinder(8.5, 6.4)
        washer = Pos(f1 + 1, y, z) * Rot(0, 90, 0) * Cylinder(10.5, 2.0)
        plate = box(a0 - 3, a0, y - 20, y + 20, z - 20, z + 20)
        nut = Pos(a0 - 3 - 4, y, z) * Rot(0, 90, 0) * Cylinder(8.5, 8.0)
        bolts.append(Compound([shank, head, washer, plate, nut]))
    pins = [rod((a0 + 2, y, ztop), (f1 - 2, y, ztop), 6.0) for y in p["pins_y"]]
    return bolts, pins
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

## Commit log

2026-10-03 LaneSkiff at TRL 3: constructable design (kit 1.7.0)
    Problem, concept and requirements; sizing calculations; CAD model, STEP and STL; general arrangement drawing; bill of materials; build plan with making sketches, joint close-ups and step pictures; design decisions register (design choices decided under Amish's 2026-10-03 pre-approval; requirement decisions open for Amish); TRL 2 and TRL 3 review; photoreal renders and storefront card. Private until Amish opens it.
    [bom.csv, hinge-rail.stl, knuckle-floor.stl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]
2026-10-04 Carry Amish's round 2 requirement decisions into the design
    Amish approved all 47 recommendations on 2026-10-03 ("i approve all of the 47 recommendations provided by you. Execute them."). Each repo gains a decision record (DDR-003, or the next free number for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
    [bom.csv, knuckle-floor.stl, laneskiff-aft-half.step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]
2026-10-04 Carry Amish's round-2 and round-3 decisions into the design
    Amish approved all 46 round-2 recommendations ("i agree with all the 46 recommendations you provided. please proceed.") and all round-3 recommendations ("For round 3, I agree with all your proposed r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
    [bom.csv, laneskiff-aft-half.step, laneskiff-assembly.step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]

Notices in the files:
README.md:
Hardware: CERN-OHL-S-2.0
